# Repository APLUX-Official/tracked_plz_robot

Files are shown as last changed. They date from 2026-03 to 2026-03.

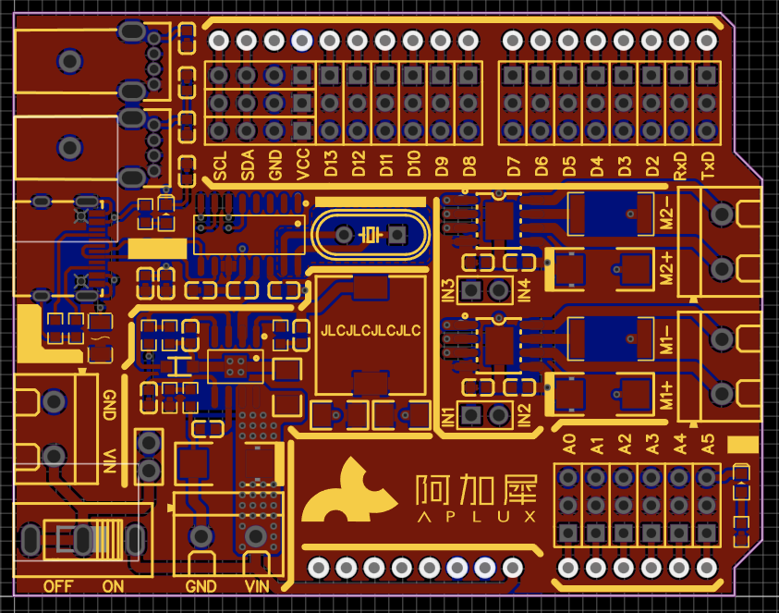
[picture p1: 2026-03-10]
image1.png

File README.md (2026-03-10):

# 🤖 Household Pet Monitoring Robot

## 1. Project Overview

This project builds an FPV desktop monitoring robot based on the **Arduino Uno Q**. It features real-time video transmission, AI object recognition, 2-axis gimbal control, and speed-adjustable omnidirectional movement.

**Core Highlights**:

* **Web Full-Stack Architecture**: Separated HTML/CSS/JS front-end with a clear structure.
* **Cyberpunk-Style Dashboard**: Responsive UI with a three-column layout on desktop, automatically optimized for mobile portrait mode.
* **Hybrid Drive Underlayer**: Resolves Arduino timer conflicts while achieving servo image stabilization and smooth motor speed regulation.
* **Offline Operation Support**: Localized front-end resources enable smooth control within the local area network (LAN) without external internet access.
* **Automatic Reconnection Under Weak Network**: Built-in reconnection mechanism for network disconnections. Control can be automatically restored after mobile phone or robot WiFi disconnection, with real-time connection status indicated by the status light.

---

## 2. Project File Structure

The project adopts a front-end and back-end separated file organization for easy maintenance:

```text
tracked_plz/
├── sketch/
│   └── sketch.ino       # Arduino underlying firmware (C++)
├── python/
│   └── main.py          # Python middle-tier logic (Socket.IO/Bridge/AI)
├── assets/              # Front-end static resources
│   ├── index.html       # Web page skeleton (Title: Desktop Monitoring Robot)
│   ├── style.css        # Stylesheet (including portrait layout optimization)
│   ├── script.js        # Interaction logic (Socket communication/debouncing)
│   └── socket.io.min.js # Local dependency library (recommended to download and place here)
└── README.md            # Project documentation
```

## 3. Hardware Architecture & Wiring

| Component | Model | Arduino Pin | Description |
| --- | --- | --- | --- |
| Main Controller | Arduino Uno Q | - | Based on STM32/Zephyr |
| Motor Driver | A4950 (Dual Channel) | - | Requires external 7.4V-12V lithium battery |
| Left Motor | Gear Motor | D5, D6 | Controls left track |
| Right Motor | Gear Motor | D9, D10 | Controls right track (reverse correction implemented in the underlying layer) |
| Gimbal Pan | SG90 Servo | D3 | Horizontal rotation (0-180°) |
| Gimbal Tilt | SG90 Servo | D11 | Vertical nodding (limited to 60-120°, midpoint at 90°) |
| Camera | USB Cam | USB Port | Video stream port: 49124 |

## 4. Software Architecture Analysis

### 4.1 Front-End (Assets)

- **Layout Logic (style.css)**: Desktop/tablet: Three-column layout (left: driving - middle: video - right: gimbal). Mobile portrait: Forced reordering to video (top) → gimbal (middle) → driving (bottom), conforming to one-handed operation habits.
- **Interaction Logic (script.js)**: Safety mechanisms: Listens to `touchcancel` and `mouseleave` events to prevent car runaway when fingers slide out of buttons. Offline-first: Prioritizes loading local `socket.io.min.js` for operation in network-free environments. Weak network reconnection: Socket.IO automatic reconnection with real-time connection status display on the UI (ONLINE/Reconnecting/Reconnection Failed).

### 4.2 Middle-Tier (Python)

- **Speed Management**: Maintains a global `current_speed` variable to receive slider values (50-255) from the front-end.
- **Command Routing**: Converts semantic commands (up, stop) from the front-end into underlying motor parameters.
- **AI Vision**: Runs object detection in the background and pushes recognition results (e.g., [TARGET] person) in real-time via Socket.

### 4.3 Underlayer (C++)

Adopts a "Hybrid Drive Mode" to resolve resource conflicts:

- **SG90 Servos**: Uses the hardware `<Servo.h>` library, occupying timers to ensure gimbal stability (no jitter).
- **DC Motors**: Uses non-blocking software PWM (based on `micros()`), avoiding the failure of hardware PWM on D9/D10 pins and achieving smooth speed regulation.

## 5. User Guide

Access the console via a browser at `http://<Robot IP>:7000`.

### 🎮 Driving Control (Left/Bottom Panel)

- **Speed Slider (Amber)**: Drag to adjust the maximum motor speed (50-255). Recommended setting: 150 for indoor use, 255 for outdoor use.
- **Direction Joystick**: Hold direction keys to move; release to stop immediately.
- **STOP Button (Red)**: Located in the center of the directional pad, click to trigger emergency stop.

### 📷 Vision System (Middle Panel)

- **Video Stream**: Low-latency real-time transmission.
- **HUD Display**: System status and AI-recognized target objects are displayed as text at the bottom.

### 🔭 Gimbal Control (Right/Middle Panel)

- **PAN (Cyan)**: Controls left/right rotation of the camera.
- **TILT (Cyan)**: Controls up/down angle of the camera (0-180°).

### 🔧 Servo Midpoint Calibration (For First-Time Installation)

A dedicated calibration module is provided at the bottom of the gimbal control panel to ensure precise servo arm posture during installation:

1. Connect the servos but do not tighten the arm fixing screws.
2. Start the program and open the web console.
3. Click "Start Calibration" → both axes automatically return to the 90° midpoint.
4. Use the ±1/±5 degree fine-tuning buttons for precise adjustment.
5. Once satisfied, fix the arm and tighten the screws.
6. Click "Complete Calibration" to exit.

## 6. Frequently Asked Questions (FAQ)

**Q: Why is the interface messed up on mobile portrait mode?**  
A: Ensure the latest `style.css` is referenced. The new stylesheet includes `@media` queries that automatically place the video at the top and buttons at the bottom.

**Q: Why does only one side of the wheels spin?**  
A: Check the battery level. The A4950 may fail to drive two motor channels simultaneously at low voltage.

**Q: Can it be used without an internet connection?**  
A: Yes. As long as `socket.io.min.js` is downloaded to the `assets` folder, the robot can be controlled via the router's LAN without internet access.

**Q: What to do if the servos jitter?**  
A: The current code has been optimized for anti-jitter. If jitter persists, check if the servos share power with the motors. It is recommended to power the servos separately or connect a filter capacitor in parallel.

**Q: Can control be automatically restored after network disconnection?**  
A: Yes. The system has a complete weak network reconnection mechanism:

- **Mobile/PC disconnection and recovery**: Socket.IO on the browser side will automatically reconnect. The status light changes from green → flashing yellow (reconnecting) → green (recovered), with the number of reconnection attempts displayed during the process.
- **Arduino UNO Q WiFi disconnection and recovery**: The same effect applies. The UNO Q hardware layer automatically reconnects to WiFi, and the browser side rebuilds communication automatically upon detecting connection recovery.
- Default reconnection strategy: Up to 30 retry attempts, with an initial interval of 1 second, exponentially backing off to a maximum of 5 seconds. If reconnection fails after 30 attempts, a prompt "Reconnection failed, please refresh the page" is displayed.
- Parameters such as `reconnectionAttempts` (number of retries), `reconnectionDelay` (initial delay), and `reconnectionDelayMax` (maximum delay) can be modified in the `io({...})` configuration at the top of `script.js`.

## 7. Quick Start

1. Upload the code in the `sketch/` directory to the Arduino board.

2. Ensure the `assets/` directory contains `index.html`, `style.css`, and `script.js`.

3. Run the Python service:

   ```bash
   python3 python/main.py
   ```

Enjoy your desktop monitoring robot!🚀

<!--
 * @Author: WALT
 * @Date: 2026-02-05 18:26:41
-->
# 🤖 FPV AI 桌面监控机器人 (Desktop Surveillance Robot)

## 1. 项目概述 (Overview)
本项目构建了一个基于 **Arduino Uno Q** 的 FPV 桌面监控机器人。它具备实时视频回传、AI 物体识别、两轴云台控制以及全向移动调速能力。

**核心亮点**：
* **Web 全栈架构**：HTML/CSS/JS 前端分离，结构清晰。
* **赛博朋克仪表盘**：响应式 UI，电脑端三栏布局，手机竖屏自动优化排序。
* **混合驱动底层**：解决了 Arduino 定时器冲突，同时实现舵机稳像与电机平滑调速。
* **离线运行支持**：前端资源本地化，无需外网即可在局域网内流畅控制。
* **弱网自动重连**：内置断网重连机制，手机断网或机器人断 WiFi 后均可自动恢复控制，状态灯实时指示连接状态。

---

## 2. 项目目录结构 (File Structure)
项目采用前后端分离的文件组织方式，便于维护：

```text
tracked_plz/
├── sketch/
│   └── sketch.ino       # Arduino 底层固件 (C++)
├── python/
│   └── main.py          # Python 中台逻辑 (Socket.IO/Bridge/AI)
├── assets/              # 前端静态资源
│   ├── index.html       # 网页骨架 (标题: 桌面监控机器人)
│   ├── style.css        # 样式表 (含竖屏布局优化)
│   ├── script.js        # 交互逻辑 (Socket通信/防抖)
│   └── socket.io.min.js # 本地依赖库 (推荐下载放置此处)
└── README.md            # 项目文档
```

## 3. 硬件架构与接线 (Hardware & Wiring)

| 组件 | 型号 | Arduino 引脚 | 说明 |
|---|---|---|---|
| 主控 | Arduino Uno Q | - | 基于 STM32/Zephyr |
| 电机驱动 | A4950 (双路) | - | 需外接 7.4V-12V 锂电池 |
| 左电机 | 减速电机 | D5, D6 | 负责左侧履带 |
| 右电机 | 减速电机 | D9, D10 | 负责右侧履带 (底层已做反向修正) |
| 云台 Pan | SG90 舵机 | D3 | 水平旋转 (0-180°) |
| 云台 Tilt | SG90 舵机 | D11 | 垂直点头 (限位 60-120°，中位 90°) |
| 摄像头 | USB Cam | USB Port | 视频流端口: 49124 |

## 4. 软件架构解析 (Software Architecture)

### 4.1 前端 (Assets)
- **布局逻辑 (style.css)**: PC/平板: 左(驾驶)-中(视频)-右(云台) 三栏布局。手机竖屏: 强制重排顺序为 视频(顶) -> 云台(中) -> 驾驶(底)，符合单手操作习惯。
- **交互逻辑 (script.js)**: 安全机制: 监听 touchcancel 和 mouseleave，防止手指滑出按钮后小车失控。离线优先: 优先加载本地 socket.io.min.js，无网环境也能跑。弱网重连: Socket.IO 自动重连并在 UI 上实时展示连接状态（ONLINE/重连中/重连失败）。

### 4.2 中台 (Python)
- **速度管理**: 维护全局 current_speed 变量，接收前端滑块数值 (50-255)。
- **指令路由**: 将前端的语义指令 (up, stop) 转换为底层电机参数。
- **AI 视觉**: 后台运行物体检测，通过 Socket 实时推送识别结果（如 [TARGET] person）。

### 4.3 底层 (C++)
采用 "混合驱动模式" (Hybrid Drive) 解决资源冲突：
- **SG90 舵机**: 使用硬件 <Servo.h> 库，占用定时器，保证云台不抖动。
- **直流电机**: 使用 非阻塞软件 PWM (基于 micros())，规避了 D9/D10 硬件 PWM 失效的问题，实现平滑调速。

## 5. 操作说明 (User Guide)
浏览器访问 `http://<机器人IP>:7000` 进入控制台。

### 🎮 驾驶控制 (左侧/下方面板)
- **速度滑块 (Amber)**: 拖动调节电机最大速度 (50-255)。建议室内设为 150，户外设为 255。
- **方向摇杆**: 按住方向键移动，松手即停。
- **STOP 按钮 (红色)**: 位于十字键中央，点击可触发急停。

### 📷 视觉系统 (中间面板)
- **视频流**: 低延迟实时回传。
- **HUD 显示**: 底部文字显示系统状态及 AI 识别到的目标物体。

### 🔭 云台控制 (右侧/中间面板)
- **PAN (青色)**: 控制摄像头左右旋转。
- **TILT (青色)**: 控制摄像头上下角度 (0-180°)。

### 🔧 舵机中位校准 (首次安装时使用)
云台控制面板下方有专用校准模块，用于确保舵机安装时摇臂姿态精确：
1. 接好舵机但不拧紧摇臂固定螺丝
2. 启动程序，打开 Web 控制台
3. 点击“开始校准”→ 双轴自动回中 90°
4. 使用 ±1/±5 度微调按钮精确调整
5. 满意后固定摇臂、拧紧螺丝
6. 点击“完成校准”退出

## 6. 常见问题 (FAQ)
**Q: 为什么手机竖屏时界面乱了？**  
A: 确保引用了最新的 style.css。新样式表包含 @media 查询，会自动将视频置顶，按钮置底。

**Q: 为什么小车只有一侧轮子转？**  
A: 检查电池电量。A4950 在低电压下可能无法同时驱动两路电机。

**Q: 没有网络可以用吗？**  
A: 可以。只要下载了 socket.io.min.js 到 assets 文件夹，机器人连接路由器的局域网即可控制，无需互联网。

**Q: 舵机抖动怎么办？**  
A: 当前代码已优化防抖。如果仍有抖动，请检查是否与电机共用了电源，建议给舵机单独供电或并联滤波电容。

**Q: 网络断开后还能自动恢复控制吗？**  
A: 可以。系统内置了完整的弱网重连机制：
- **手机/电脑断网再恢复**：浏览器端 Socket.IO 会自动重连，状态灯从绿色→黄色闪烁（重连中）→绿色（恢复），期间可看到重连次数。
- **Arduino UNO Q 断 WiFi 再恢复**：效果相同。UNO Q 硬件层自动重连 WiFi，浏览器端检测到连接恢复后自动重建通信。
- 默认重连策略：最多重试 30 次，首次间隔 1 秒，指数退避至最大 5 秒。超过 30 次未成功则提示"重连失败，请刷新页面"。
- 可在 `script.js` 顶部的 `io({...})` 配置中修改 `reconnectionAttempts`（重试次数）、`reconnectionDelay`（首次延迟）、`reconnectionDelayMax`（最大延迟）等参数。

## 7. 快速启动
1. 将 sketch/ 目录下的代码上传至 Arduino。
2. 确保 assets/ 目录下有 index.html, style.css, script.js。
3. 运行 Python 服务：
   ```bash
   python3 python/main.py
   ```

享受你的桌面监控机器人！🚀

文档生成时间: 2026-02-05

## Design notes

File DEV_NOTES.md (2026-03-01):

# Arduino FPV 履带机器人 - 开发问题与解决方案记录

## 1. 硬件引脚定义问题
**问题描述**：
在使用 A4950 电机驱动时，使用代码 `const int PIN = 5;` 无法控制电机。
**原因分析**：
Arduino Uno Q (基于 STM32/Zephyr) 的底层引脚映射与传统 AVR Uno 不同。纯数字 `5` 指向的是芯片内部 GPIO 索引，而非板载丝印 `D5`。
**解决方案**：
必须使用带 `D` 前缀的常量定义。
- ❌ 错误：`const int PIN = 5;`
- ✅ 正确：`const int PIN = D5;`

## 2. 电机对向安装导致的逻辑冲突
**问题描述**：
发送“前进”指令时，小车原地打转；发送“左转”时小车前后拉扯。
**原因分析**：
履带底盘左右电机通常是**镜像对称安装**（背对背）。给同样的电平信号（例如都给正电压），物理上它们会朝相反的方向旋转。
**解决方案**：
在 C++ 底层驱动中，对右轮逻辑进行**反向处理**。
- 左轮：`Speed > 0` -> 正转逻辑
- 右轮：`Speed > 0` -> 反转逻辑

## 3. Servo 库与 analogWrite 的资源冲突
**问题描述**：
当代码中引入 `<Servo.h>` 并 attach 舵机后，原本控制电机的 `analogWrite()` 失效，电机不动。
**原因分析**：
`Servo` 库为了生成精准的 50Hz PWM 信号，占用了单片机的**硬件定时器 (Timer)**。在 Arduino 架构中，该定时器往往也负责特定引脚（如 D9, D10）的硬件 PWM 生成。定时器被抢占后，`analogWrite` 无法输出波形。
**解决方案**：
放弃 `analogWrite`，改用**非阻塞式软件 PWM**。利用 `micros()` 获取系统时间，手动快速翻转引脚电平来模拟 PWM 波形。

## 4. 舵机抖动 (Jitter)
**问题描述**：
舵机在静止时不断抽搐、抖动。
**原因分析**：
1. **代码阻塞**：使用了 `delay()` 或 `for` 循环来生成电机 PWM，导致 CPU 无法及时响应 Servo 的信号维持中断。
2. **电源噪声**：直流电机启动时的电流冲击干扰了舵机供电。
**解决方案**：
1. **代码优化**：移除所有 `delay()` 和死循环，使用非阻塞逻辑（见解决方案3）。
2. **硬件滤波**（建议）：在舵机电源处并联电解电容。

---

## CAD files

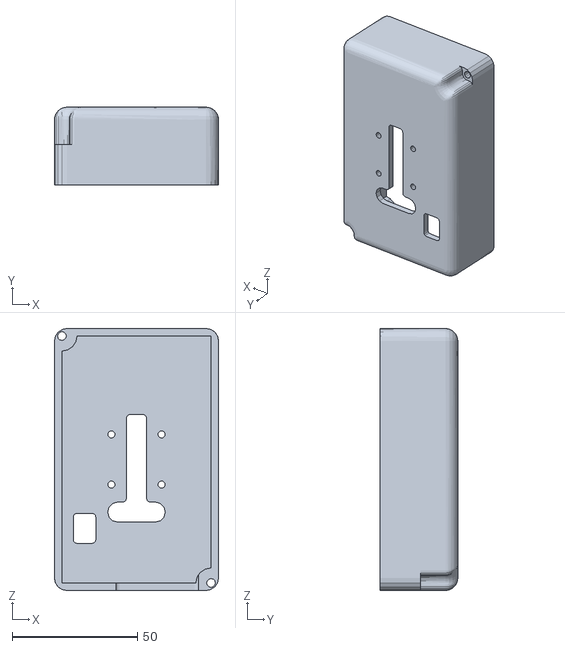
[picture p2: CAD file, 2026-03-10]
models/云台盖.STL
65.5 x 31.0 x 104.6

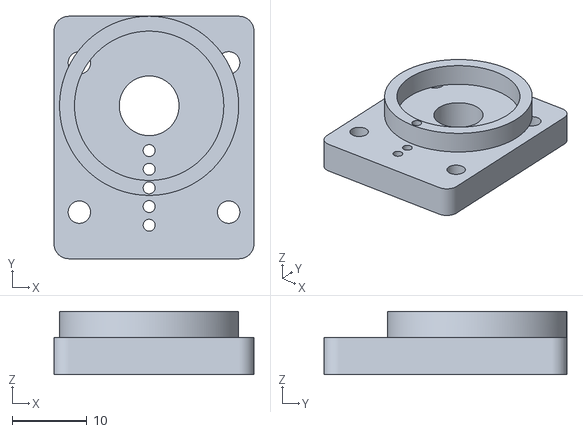
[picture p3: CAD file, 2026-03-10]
models/车云台底部.stl
26.8 x 32.5 x 8.50

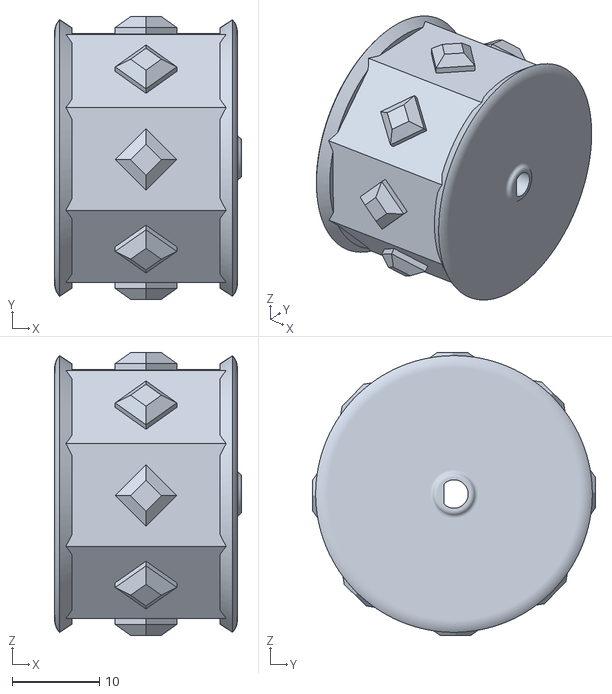
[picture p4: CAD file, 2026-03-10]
models/master_wheel.stl
21.5 x 32.5 x 32.5

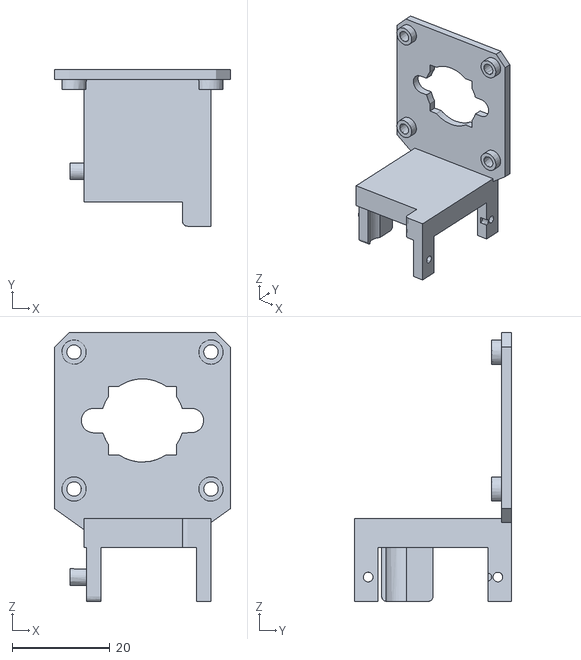
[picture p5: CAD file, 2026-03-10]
models/云台相机支架融合2.0.stl
36.0 x 32.0 x 55.0

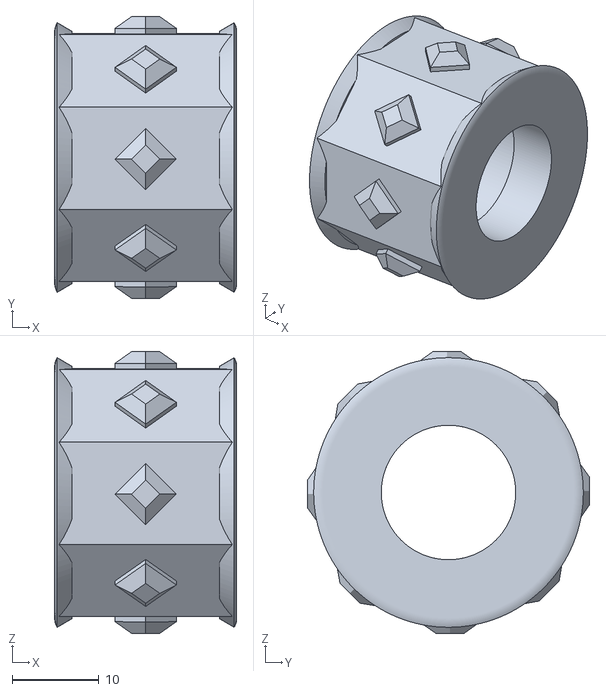
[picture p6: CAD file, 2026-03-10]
models/slave_wheel_SL.stl
21.0 x 32.5 x 32.5

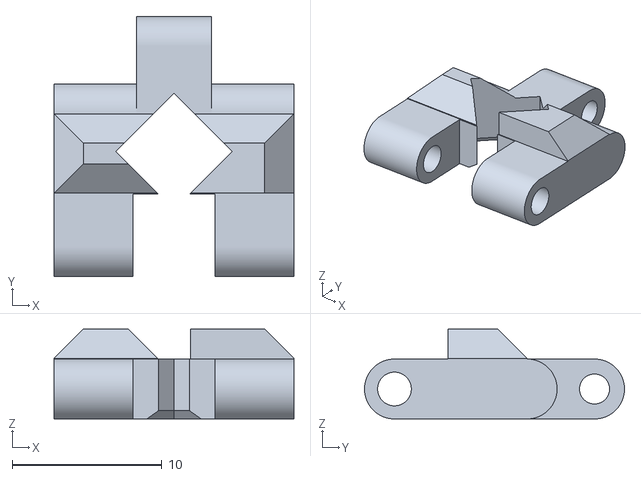
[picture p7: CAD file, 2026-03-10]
models/mechanical_track.stl
16.0 x 17.4 x 6.00

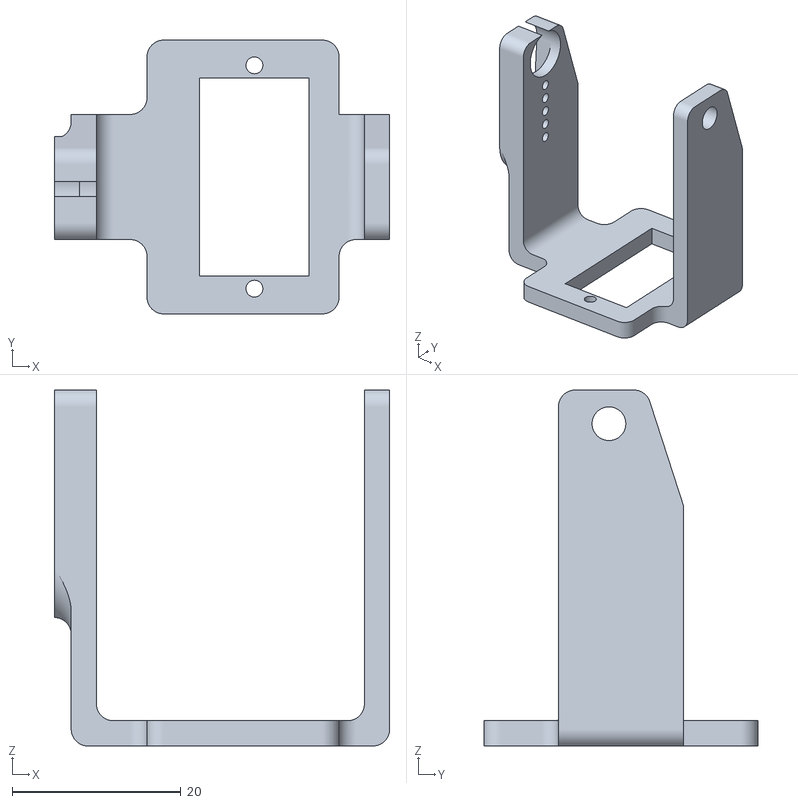
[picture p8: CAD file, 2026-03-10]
models/车云台中间部件.stl
39.8 x 32.5 x 42.2

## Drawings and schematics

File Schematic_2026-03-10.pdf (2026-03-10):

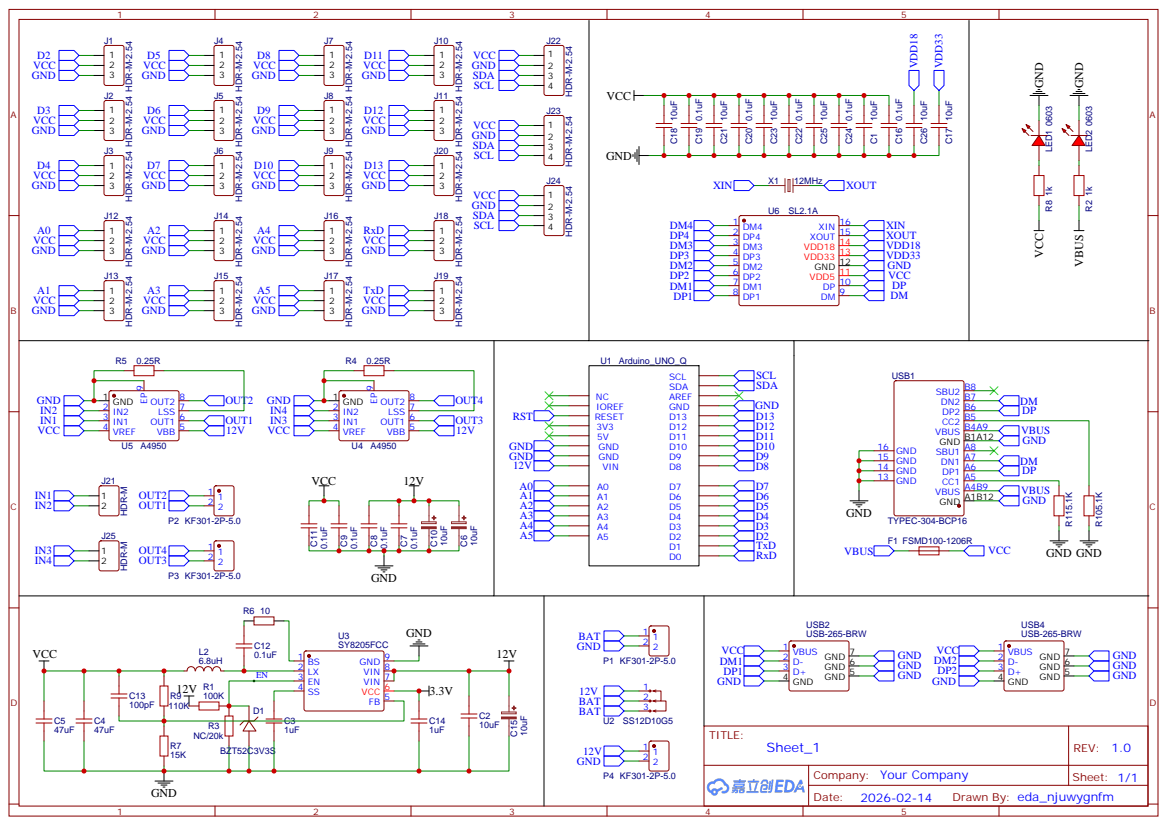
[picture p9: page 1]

DP 10 VDD5 11 GND 12 VDD33 13 VDD18 14 XOUT 15 XIN 16

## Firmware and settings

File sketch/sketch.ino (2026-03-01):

/*
 * @Author: WALT
 * @Date: 2026-02-05 17:54:02
 */
// SPDX-FileCopyrightText: Copyright (C) ARDUINO SRL (http://www.arduino.cc)
// SPDX-License-Identifier: MPL-2.0

#include <MsgPack.h>
#include <Arduino_RPClite.h> 
#include "Arduino_RouterBridge.h"
#include <Servo.h>

// === 硬件引脚 ===
const int PIN_L1 = D5;
const int PIN_L2 = D6;
const int PIN_R1 = D9;
const int PIN_R2 = D10;
const int PIN_PAN = D3; // 云台 Pan
const int PIN_TILT = D11; // 云台 Tilt

Servo servoPan;
Servo servoTilt;

// 目标速度
volatile int target_speed_l = 0;
volatile int target_speed_r = 0;

void setup() {
    Serial.begin(9600);
    
    pinMode(PIN_L1, OUTPUT);
    pinMode(PIN_L2, OUTPUT);
    pinMode(PIN_R1, OUTPUT);
    pinMode(PIN_R2, OUTPUT);

    servoPan.attach(PIN_PAN);
    servoTilt.attach(PIN_TILT);
    servoPan.write(90);
    servoTilt.write(90);

    Bridge.begin();
    Bridge.provide("motor_l", set_motor_l);
    Bridge.provide("motor_r", set_motor_r);
    Bridge.provide("servo_pan", set_servo_pan);
    Bridge.provide("servo_tilt", set_servo_tilt);
}

void loop() {
    Bridge.update(); 

    // === 非阻塞软件 PWM (核心黑科技) ===
    // 我们手动制造 PWM 波形，但不使用 delay()，也不依赖 analogWrite
    
    unsigned long now = micros(); // 获取当前微秒数
    const int period = 2000; // PWM 周期 2000us = 2ms (500Hz)
    
    // 计算当前周期内的“时间点” (0 ~ 1999)
    long cycle_time = now % period; 

    // 计算高电平持续时间
    int on_time_l = abs(target_speed_l) * period / 255;
    int on_time_r = abs(target_speed_r) * period / 255;

    // --- 左轮控制 ---
    if (target_speed_l == 0) {
        digitalWrite(PIN_L1, LOW); digitalWrite(PIN_L2, LOW);
    } else {
        // 判断方向
        int pin_pwm = (target_speed_l < 0) ? PIN_L1 : PIN_L2; // 你的逻辑：<0 前进
        int pin_low = (target_speed_l < 0) ? PIN_L2 : PIN_L1;
        
        // 关键：根据时间点决定是 HIGH 还是 LOW
        digitalWrite(pin_low, LOW); // 另一端永远拉低
        digitalWrite(pin_pwm, (cycle_time < on_time_l) ? HIGH : LOW);
    }

    // --- 右轮控制 ---
    if (target_speed_r == 0) {
        digitalWrite(PIN_R1, LOW); digitalWrite(PIN_R2, LOW);
    } else {
        // 判断方向 (注意右轮反向逻辑)
        // 你的逻辑：<0 前进 (对应右轮物理反向，所以这里引脚逻辑要反着写)
        // 原本 <0 是 R1=LOW, R2=HIGH。现在我们要对 High 的那个脚切片
        int pin_pwm = (target_speed_r < 0) ? PIN_R2 : PIN_R1; 
        int pin_low = (target_speed_r < 0) ? PIN_R1 : PIN_R2;

        digitalWrite(pin_low, LOW);
        digitalWrite(pin_pwm, (cycle_time < on_time_r) ? HIGH : LOW);
    }
}

// === Bridge 回调 (只负责更新变量) ===
void set_motor_l(int speed) { target_speed_l = constrain(speed, -255, 255); }
void set_motor_r(int speed) { target_speed_r = constrain(speed, -255, 255); }
void set_servo_pan(int angle) { servoPan.write(constrain(angle, 0, 180)); }
void set_servo_tilt(int angle) { servoTilt.write(constrain(angle, 60, 120)); }
